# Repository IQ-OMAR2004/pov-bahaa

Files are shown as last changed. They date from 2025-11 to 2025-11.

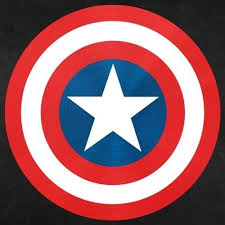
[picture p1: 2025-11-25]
images/captain_america.jpeg

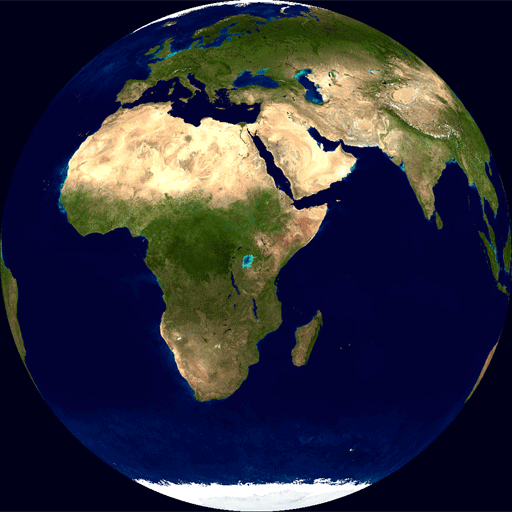
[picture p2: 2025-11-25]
gif_sequences/earth/frame_16.png

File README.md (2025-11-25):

# POV Holographic Fan Display

A Persistence of Vision (POV) display system for Raspberry Pi with WS2815 LED strips.
HEllo from bahaa
## Features

- **Static Images**: Display pre-processed images from `.npy` files
- **GIF Animations**: Play animated sequences
- **Shape Generation**: Built-in circle and square shapes
- **Button Controls**: Switch modes with physical buttons
- **Robust Timing**: Noise filtering and RPM smoothing for stable display
- **Configurable**: Easy configuration through `config.py`

## Hardware Requirements

### Components

| Component | Specification | GPIO Pin |
|---|---|---|
| LED Strip | WS2815, 72 LEDs | GPIO 18 (PWM) |
| Hall Sensor | A3144 or similar | GPIO 4 |
| Button 1 | Circle mode | GPIO 17 |
| Button 2 | Square mode | GPIO 27 |
| Button 3 | Image/GIF cycle | GPIO 22 |

### Wiring Diagram

```
Raspberry Pi               Components
─────────────              ──────────
GPIO 18 (Pin 12) ────────> LED Strip Data In
GPIO 4  (Pin 7)  ────────> Hall Sensor Output
GPIO 17 (Pin 11) ────────> Button 1 (to GND)
GPIO 27 (Pin 13) ────────> Button 2 (to GND)
GPIO 22 (Pin 15) ────────> Button 3 (to GND)
5V      (Pin 2)  ────────> LED Strip VCC
GND     (Pin 6)  ────────> LED Strip GND, Hall Sensor GND
3.3V    (Pin 1)  ────────> Hall Sensor VCC
```

### Notes

- **Power**: WS2815 LEDs require 12V power supply. Use a separate power supply for the LED strip, sharing only GND with the Pi.
- **Level Shifter**: Recommended for 3.3V to 5V data line conversion (though many WS2815 work without it).
- **Hall Sensor**: Place magnet on rotating blade to trigger once per rotation.
- **Buttons**: Connect between GPIO and GND (internal pull-ups are enabled).

## Installation

### 1. Clone or copy the project

```bash
cd /home/pi
git clone <repository-url> POV-new
cd POV-new
```

### 2. Install dependencies

```bash
sudo pip3 install -r requirements.txt
```

### 3. Enable SPI/PWM (if not already)

```bash
sudo raspi-config
# Navigate to: Interface Options > SPI > Enable
# Reboot after changes
```

## Configuration

Edit `config.py` to customize your setup:

```python
# Key settings to adjust:

NUM_LEDS = 72              # Number of LEDs on your strip
NUM_DIVISIONS = 100        # Angular resolution (reduce for faster motors)
BRIGHTNESS_RATIO = 0.3     # Brightness (0.0-1.0)
DEFAULT_RPM = 600          # Expected motor RPM
LINES_TO_SHIFT = -15       # Adjust if image appears rotated
```

### RPM vs Divisions Guide

| Motor RPM | Recommended Divisions |
|---|---|
| 300-600 | 100 (best quality) |
| 600-900 | 50 |
| 900-1200  | 36 |
| 1200-1500 | 24 |
| 1500+ | 16 |

## Usage

### Running the Display

```bash
# Must run as root for GPIO/PWM access
sudo python3 pov_display.py
```

### Controls

- **Button 1 (GPIO 17)**: Switch to circle mode (press again to change color)
- **Button 2 (GPIO 27)**: Switch to square mode (press again to change color)
- **Button 3 (GPIO 22)**: Cycle through images and GIF sequences

### Keyboard

- **Ctrl+C**: Graceful shutdown

## Processing Your Own Images

### Static Images

1. Place your image in the `images/` folder
2. Run the processor:

```bash
python3 process_image.py images/myimage.png
```

3. Output saves to `colors/douple_resolution/douple_res_myimage.npy`

### GIF Animations

1. Place your GIF in the `gifs/` folder
2. Run the processor:

```bash
python3 process_gif.py gifs/myanimation.gif
```

3. Output saves to `gif_colors/myanimation/`

### Image Tips

- **Square images** work best (circular crop is applied)
- **Simple, high-contrast** designs are most visible
- **Centered designs** display better
- Image is sampled radially from center outward

## File Structure

```
POV-new/
├── pov_display.py          # Main display script
├── config.py               # Configuration settings
├── process_image.py        # Static image processor
├── process_gif.py          # GIF/animation processor
├── requirements.txt        # Python dependencies
├── README.md               # This file
├── images/                 # Source images
│   └── Smiley_face.png
├── colors/                 # Processed static images
│   └── douple_resolution/
│       └── douple_res_Smiley_face.npy
├── gifs/                   # Source GIF files
│   └── earth.gif
├── gif_sequences/          # Extracted GIF frames
│   └── earth/
├── gif_colors/             # Processed GIF sequences
│   └── earth/
└── 3d_printing_files/      # CAD files for hardware
```

## Troubleshooting

### Display not showing / flickering

1. **Check power supply**: LEDs need adequate current (72 LEDs × 60mA = 4.3A max)
2. **Reduce brightness**: Lower `BRIGHTNESS_RATIO` in `config.py`
3. **Reduce divisions**: Lower `NUM_DIVISIONS` for faster motors
4. **Check connections**: Ensure GND is shared between Pi and LED strip

### Image appears rotated

Adjust `LINES_TO_SHIFT` in `config.py` (positive or negative values)

### Unstable RPM readings

1. Check hall sensor placement and magnet strength
2. Increase `HALL_DEBOUNCE_US` in config
3. Increase `RPM_HISTORY_SIZE` for more smoothing

### Colors look wrong

Your LED strip might use RGB instead of GRB. Set `LED_IS_GRB = False` in `config.py`

### Permission denied

Always run with `sudo`:
```bash
sudo python3 pov_display.py
```

## Advanced: Creating Custom Shapes

You can add custom shape generators in `pov_display.py`:

```python
def generate_custom_shape(color_rgb=(255, 255, 255)):
    data = []
    for angle_idx in range(NUM_DIVISIONS):
        line = [make_color(0, 0, 0)] * NUM_LEDS
        # Your shape logic here
        # Set pixels: line[led_position] = make_color(r, g, b)
        data.append(line)
    return data
```

## License

MIT License - Feel free to modify and share!

## Credits

Combined from POV-new and Pov-fan projects for optimal performance.

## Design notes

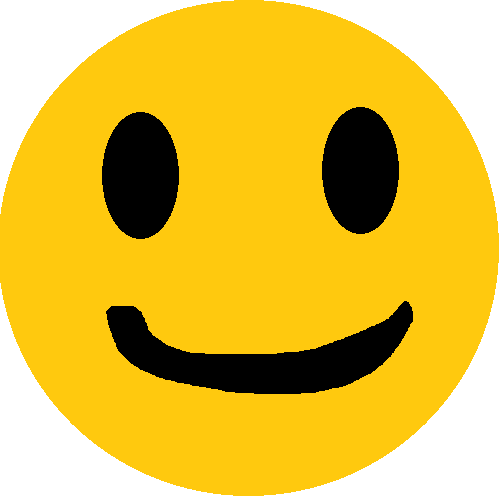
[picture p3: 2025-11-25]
images/Smiley_face.png

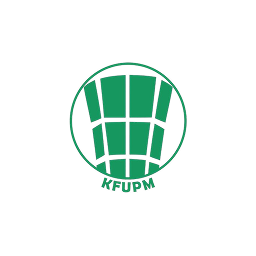
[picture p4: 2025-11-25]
images/kfupm_pp.png

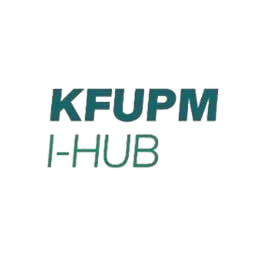
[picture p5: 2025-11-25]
images/kfupmihub.png

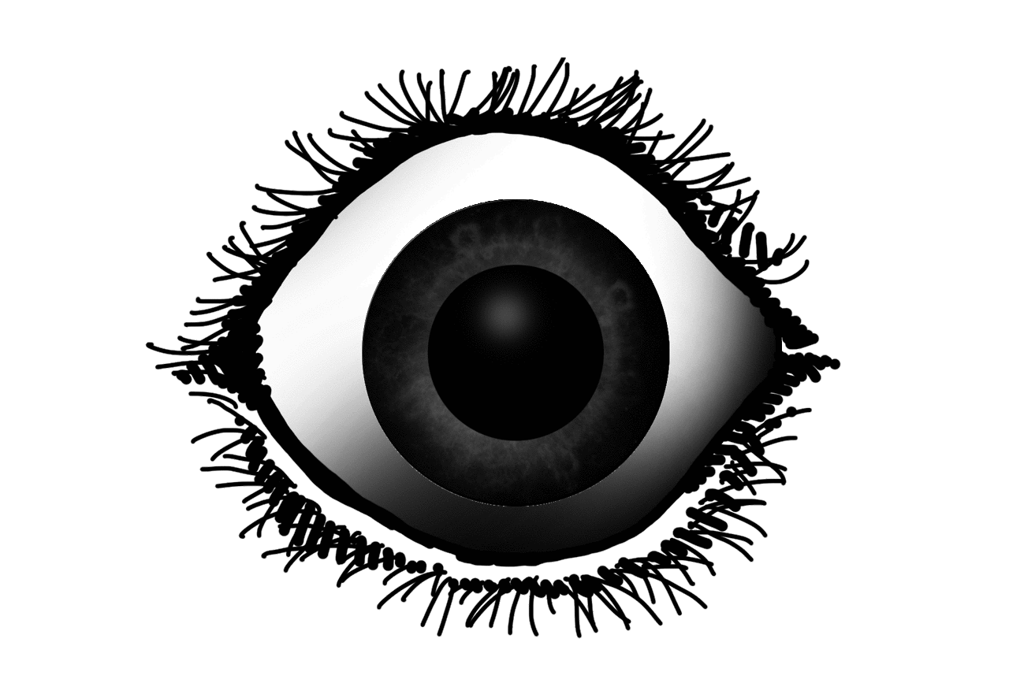
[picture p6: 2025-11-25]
gif_sequences/eyegif/frame_5.png

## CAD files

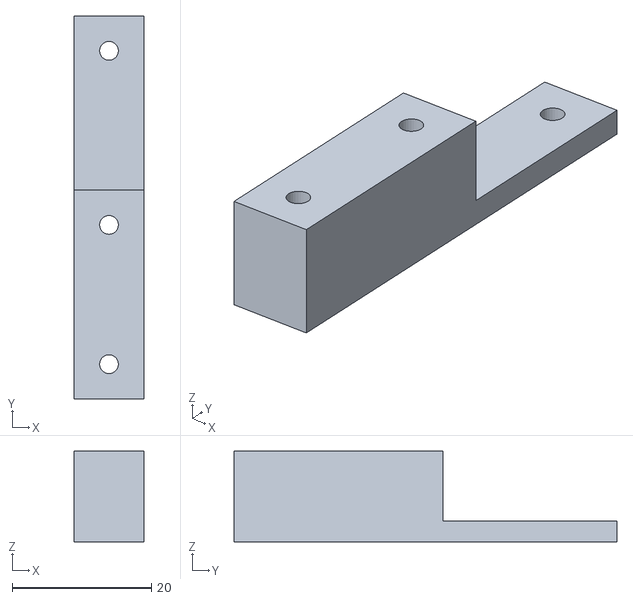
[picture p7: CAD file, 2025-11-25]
3d_printing_files/sensor_connector.stl
10.0 x 55.0 x 13.0

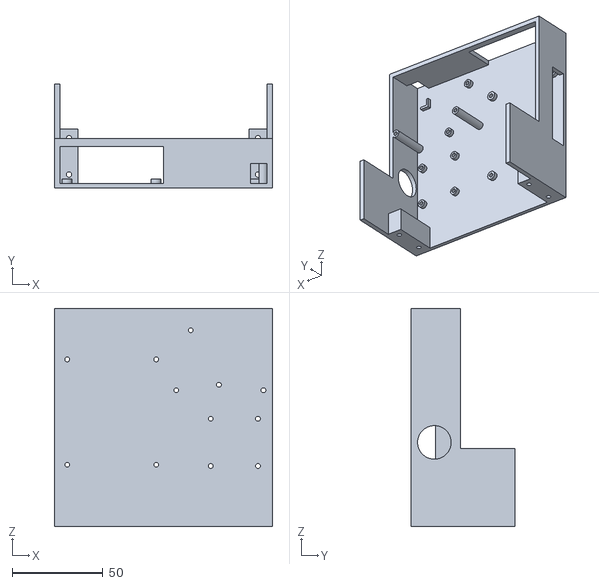
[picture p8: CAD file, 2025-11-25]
3d_printing_files/base_blue_print.STL
120.0 x 57.5 x 120.0

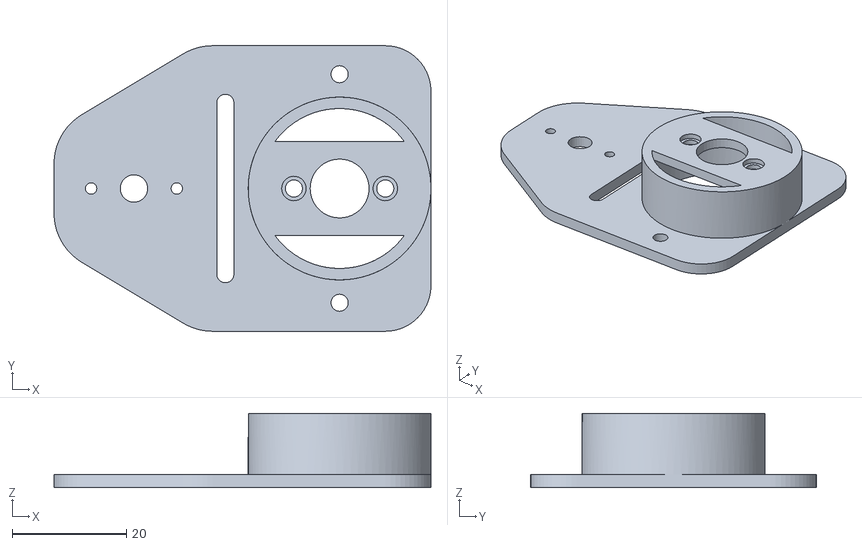
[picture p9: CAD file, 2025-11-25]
3d_printing_files/fan_motor_connector v5.stl
66.0 x 50.0 x 13.0

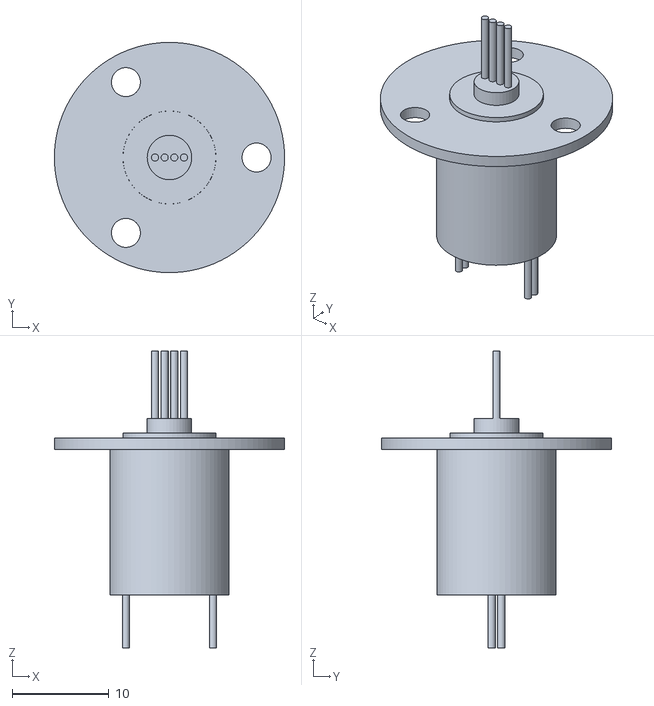
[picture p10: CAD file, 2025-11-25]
3d_printing_files/Slip_ring v1.stl
23.8 x 23.8 x 30.7

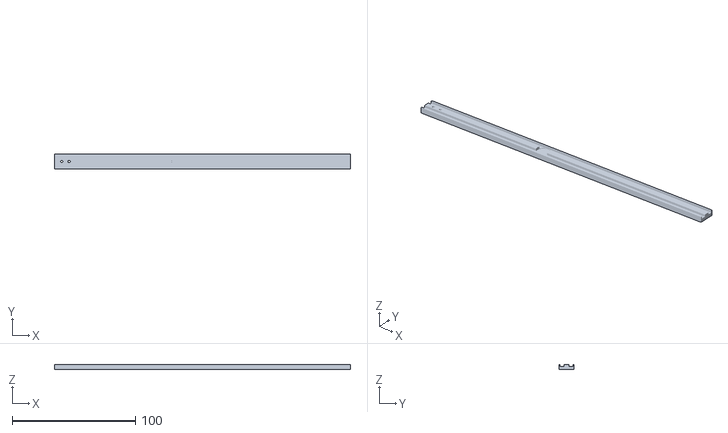
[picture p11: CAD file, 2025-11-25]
3d_printing_files/Blad v4.stl
240.0 x 12.0 x 4.13

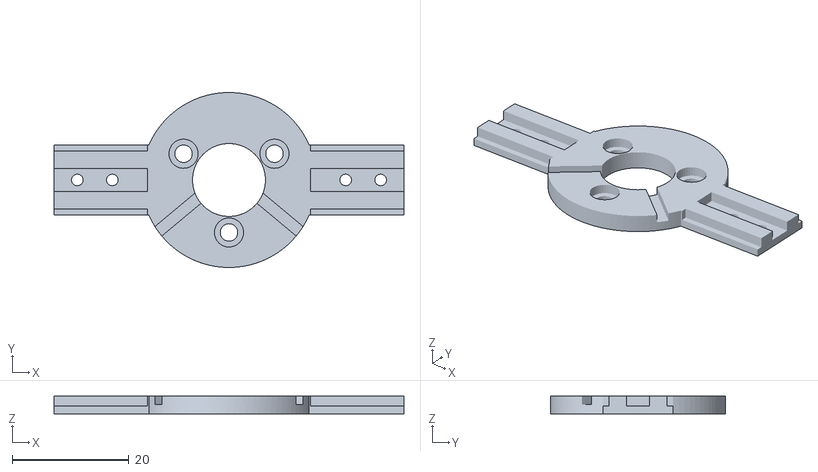
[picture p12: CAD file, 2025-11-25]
3d_printing_files/fan_blades_holder v1.stl
60.0 x 30.0 x 3.00

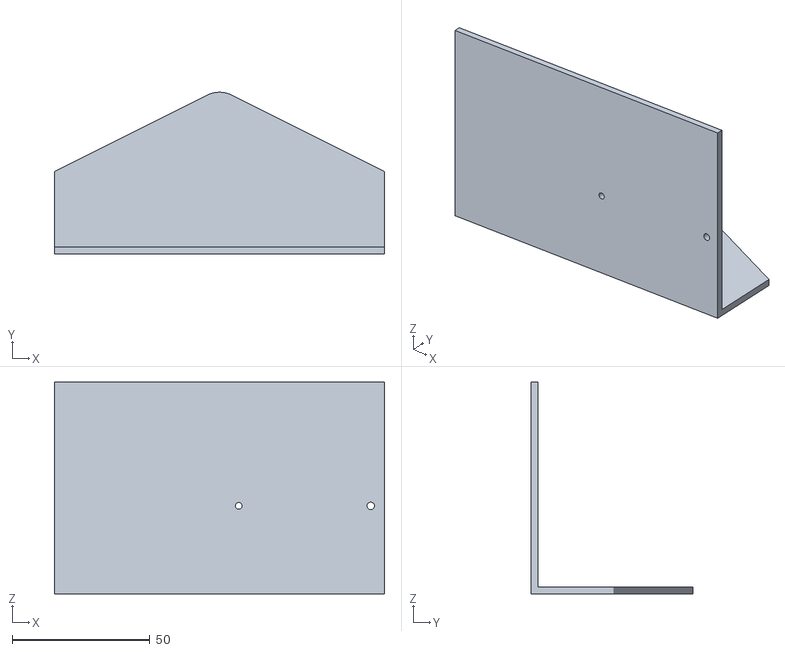
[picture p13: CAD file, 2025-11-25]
3d_printing_files/base_cover.STL
120.0 x 58.8 x 77.0

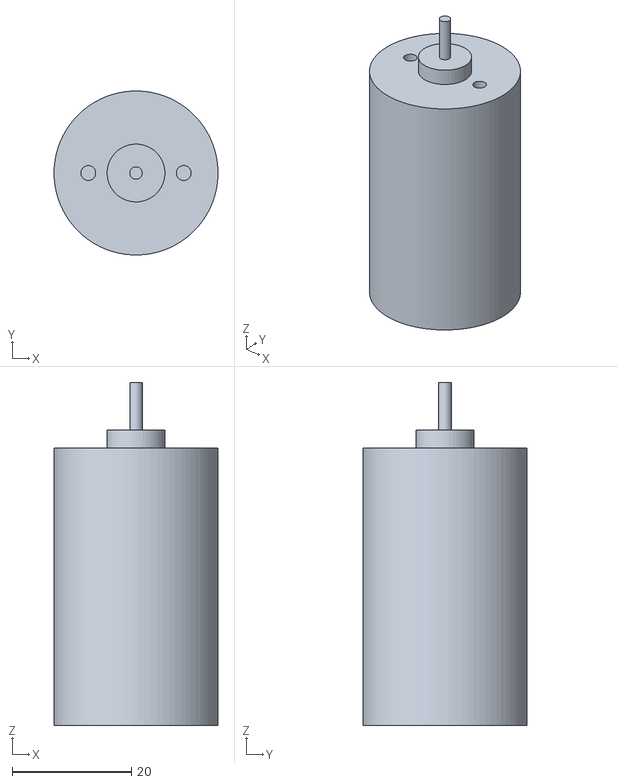
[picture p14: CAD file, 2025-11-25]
3d_printing_files/Large_motor v1.stl
27.5 x 27.5 x 57.5

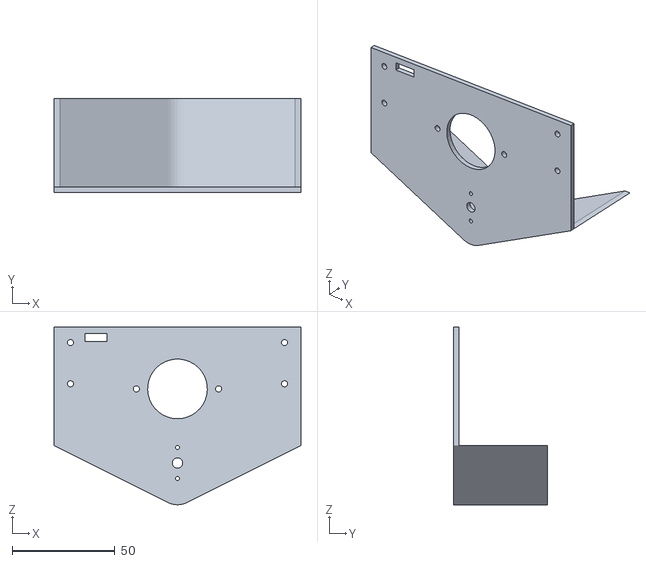
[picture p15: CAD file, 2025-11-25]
3d_printing_files/base_front.STL
120.0 x 45.5 x 86.3

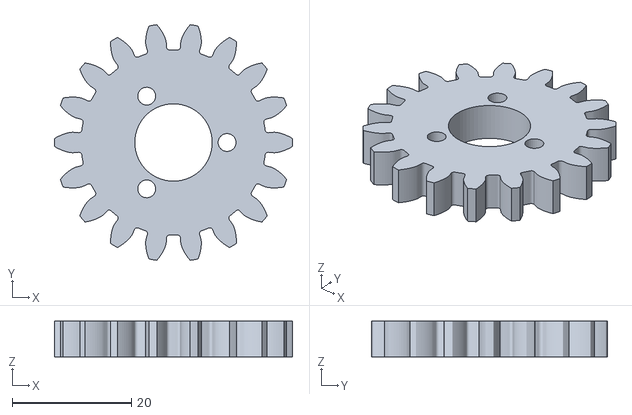
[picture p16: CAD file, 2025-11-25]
3d_printing_files/Gear_1 v3.stl
40.0 x 39.6 x 6.00

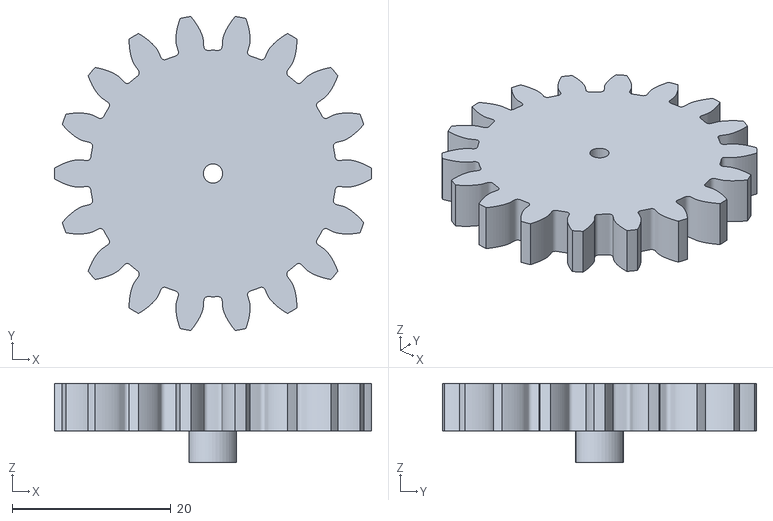
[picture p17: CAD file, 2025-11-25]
3d_printing_files/Gear_2 v3.stl
40.0 x 39.6 x 10.0

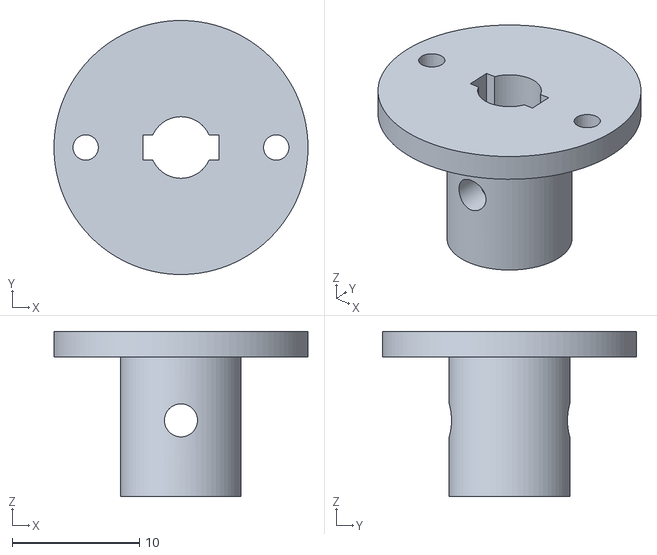
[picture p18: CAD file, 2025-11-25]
3d_printing_files/slip_ring_extension v7.stl
20.0 x 20.0 x 13.0

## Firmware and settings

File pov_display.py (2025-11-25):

#!/usr/bin/env python3
"""
POV Holographic Fan Display - Combined & Optimized
===================================================
Combines functionality from POV-new (image/GIF loading) with 
Pov-fan hardware configuration (pins, buttons, timing).

Features:
- Load pre-processed .npy images (static images)
- GIF/animation sequence playback
- Shape generation (circle, square)
- Button controls for mode switching
- Robust RPM filtering and noise rejection
- Optimized timing for stable display

Hardware:
- WS2815 LED Strip (72 LEDs) on GPIO 18
- Hall Sensor (A3144) on GPIO 4
- Button 1 (Circle) on GPIO 17
- Button 2 (Square) on GPIO 27  
- Button 3 (Image/Next) on GPIO 22

Author: Combined from POV-new and Pov-fan projects
"""

import time
import os
import math
import threading
from rpi_ws281x import PixelStrip, Color
import numpy as np
import RPi.GPIO as GPIO

# ============== LOAD CONFIGURATION ==============
# Try to import from config.py, fall back to defaults if not found
try:
    from config import (
        NUM_LEDS, LED_PIN, LED_FREQ_HZ, LED_DMA, LED_BRIGHTNESS,
        LED_INVERT, LED_CHANNEL, LED_IS_GRB,
        HALL_SENSOR_PIN, BUTTON_CIRCLE, BUTTON_SQUARE, BUTTON_IMAGE,
        NUM_DIVISIONS, BRIGHTNESS_RATIO, LINES_TO_SHIFT,
        LED_UPDATE_TIME_US, DEFAULT_RPM, MIN_RPM, MAX_RPM, TIMING_MARGIN_US,
        HALL_DEBOUNCE_US, MAX_RPM_CHANGE_PERCENT, RPM_HISTORY_SIZE,
        STATIC_IMAGES_PATH, GIF_COLORS_PATH, ROT_PER_FRAME,
        BUTTON_DEBOUNCE_TIME
    )
    print("✓ Loaded configuration from config.py")
except ImportError:
    print("⚠ config.py not found, using default values")
    # ============== DEFAULT CONFIGURATION ==============
    NUM_LEDS = 72
    LED_PIN = 18
    LED_FREQ_HZ = 800000
    LED_DMA = 10
    LED_BRIGHTNESS = 150
    LED_INVERT = False
    LED_CHANNEL = 0
    LED_IS_GRB = True
    HALL_SENSOR_PIN = 4
    BUTTON_CIRCLE = 17
    BUTTON_SQUARE = 27
    BUTTON_IMAGE = 22
    NUM_DIVISIONS = 100
    BRIGHTNESS_RATIO = 0.3
    LINES_TO_SHIFT = -15
    LED_UPDATE_TIME_US = 2800
    DEFAULT_RPM = 600
    MIN_RPM = 200
    MAX_RPM = 1500
    TIMING_MARGIN_US = 300
    HALL_DEBOUNCE_US = 5000
    MAX_RPM_CHANGE_PERCENT = 40
    RPM_HISTORY_SIZE = 15
    STATIC_IMAGES_PATH = "colors/douple_resolution/"
    GIF_COLORS_PATH = "gif_colors/"
    ROT_PER_FRAME = 4
    BUTTON_DEBOUNCE_TIME = 0.3

# ============== GLOBAL VARIABLES ==============

# Display modes
MODES = ["circle", "square", "static_image", "gif_sequence"]
current_mode_index = 0
current_mode = MODES[0]

# Image/sequence data
static_images = []               # List of available static images
gif_sequences = []               # List of available GIF sequences
current_static_index = 0
current_gif_index = 0
current_frame_index = 0
rot_per_frame = ROT_PER_FRAME    # Rotations before advancing GIF frame

# Display buffer
display_data = []                # Current frame to display [divisions][leds]
sequence_colors = []             # All frames for GIF sequence

# Timing variables
last_rotation_micros = 0
rotation_time_micros = int(60_000_000 / DEFAULT_RPM)
time_per_line_micros = rotation_time_micros // NUM_DIVISIONS
current_line = 0
rotation_active = False

# RPM tracking
current_rpm = DEFAULT_RPM
stable_rpm = DEFAULT_RPM
rpm_history = []
last_rpm_print_time = time.monotonic()


# Counters
rotation_count = 0
valid_rotation_count = 0
noise_rejected_count = 0
missed_lines_count = 0

# Hall sensor tracking
last_hall_state = GPIO.LOW
last_hall_trigger_time = 0

# Button tracking
last_button_states = {
    BUTTON_CIRCLE: GPIO.HIGH,
    BUTTON_SQUARE: GPIO.HIGH,
    BUTTON_IMAGE: GPIO.HIGH
}
last_button_time = {
    BUTTON_CIRCLE: 0,
    BUTTON_SQUARE: 0,
    BUTTON_IMAGE: 0
}
DEBOUNCE_TIME = BUTTON_DEBOUNCE_TIME

# Threading event for rotation sync
rotation_end_event = threading.Event()



# ============== GPIO SETUP ==============
GPIO.setmode(GPIO.BCM)
GPIO.setwarnings(False)

try:
    GPIO.cleanup()
    time.sleep(0.1)
except:
    pass

GPIO.setmode(GPIO.BCM)
GPIO.setup(HALL_SENSOR_PIN, GPIO.IN, pull_up_down=GPIO.PUD_DOWN)
GPIO.setup(BUTTON_CIRCLE, GPIO.IN, pull_up_down=GPIO.PUD_UP)
GPIO.setup(BUTTON_SQUARE, GPIO.IN, pull_up_down=GPIO.PUD_UP)
GPIO.setup(BUTTON_IMAGE, GPIO.IN, pull_up_down=GPIO.PUD_UP)

# Initialize LED strip
strip = PixelStrip(NUM_LEDS, LED_PIN, LED_FREQ_HZ, LED_DMA, LED_INVERT, LED_BRIGHTNESS, LED_CHANNEL)
strip.begin()


# ============== UTILITY FUNCTIONS ==============

def make_color(r, g, b):
    """Create color value handling GRB vs RGB order"""
    if LED_IS_GRB:
        return Color(int(g), int(r), int(b))
    else:
        return Color(int(r), int(g), int(b))


def clear_strip():
    """Turn off all LEDs"""
    for i in range(NUM_LEDS):
        strip.setPixelColor(i, make_color(0, 0, 0))
    strip.show()


def get_time_micros():
    """Get current time in microseconds"""
    return int(time.perf_counter() * 1_000_000)


def precise_micros_delay(micros_to_delay):
    """Precise busy-wait delay in microseconds"""
    start = time.perf_counter() * 1_000_000
    while (time.perf_counter() * 1_000_000 - start) < micros_to_delay:
        if rotation_end_event.is_set():
            break


# ============== FILE DISCOVERY ==============

def discover_static_images():
    """Find all .npy files in the static images directory"""
    global static_images
    static_images = []
    
    if os.path.exists(STATIC_IMAGES_PATH):
        for f in sorted(os.listdir(STATIC_IMAGES_PATH)):
            if f.endswith('.npy'):
                static_images.append(f)
    
    print(f"Found {len(static_images)} static images")
    return static_images


def discover_gif_sequences():
    """Find all GIF sequence folders"""
    global gif_sequences
    gif_sequences = []
    
    if os.path.exists(GIF_COLORS_PATH):
        for d in sorted(os.listdir(GIF_COLORS_PATH)):
            path = os.path.join(GIF_COLORS_PATH, d)
            if os.path.isdir(path):
                # Check if it has .npy files
                npy_files = [f for f in os.listdir(path) if f.endswith('.npy')]
                if npy_files:
                    gif_sequences.append(d)
    
    print(f"Found {len(gif_sequences)} GIF sequences")
    return gif_sequences


# ============== NPY IMAGE LOADING (from POV-new) ==============

def load_npy_image(npy_path):
    """
    Load a pre-processed .npy image file and convert to display format.
    
    The .npy files contain color data in format:
    [num_divisions][num_leds][3] where [3] is RGB
    """
    try:
        slices_colors = np.load(npy_path)
        slices_colors = slices_colors.tolist()
        return arrange_colors_for_display(slices_colors)
    except Exception as e:
        print(f"Error loading {npy_path}: {e}")
        return None


def arrange_colors_for_display(slices_colors):
    """
    Arrange colors from .npy format to display format.
    Handles the two-sided LED strip arrangement.
    
    The strip has two halves:
    - LEDs 0 to 35: One side (inner to outer)
    - LEDs 36 to 71: Other side (inner to outer)
    """
    arranged_colors = []
    num_leds_one_side = NUM_LEDS // 2
    num_divs = len(slices_colors)
    
    for line_iter in range(num_divs):
        line_array = [make_color(0, 0, 0) for _ in range(NUM_LEDS)]
        
        # First half of strip (reversed - outer LEDs first in data)
        for i in range(num_leds_one_side):
            if i * 2 + 1 < len(slices_colors[line_iter]):
                color_arr = slices_colors[line_iter][i * 2 + 1]
                color = make_color(
                    int(color_arr[0] * BRIGHTNESS_RATIO),
                    int(color_arr[1] * BRIGHTNESS_RATIO),
                    int(color_arr[2] * BRIGHTNESS_RATIO)
                )
                line_array[num_leds_one_side - i - 1] = color
        
        # Second half of strip (opposite angle, 180 degrees offset)
        opposite_line = (line_iter + num_divs // 2) % num_divs
        for i in range(num_leds_one_side):
            if i * 2 < len(slices_colors[opposite_line]):
                color_arr = slices_colors[opposite_line][i * 2]
                color = make_color(
                    int(color_arr[0] * BRIGHTNESS_RATIO),
                    int(color_arr[1] * BRIGHTNESS_RATIO),
                    int(color_arr[2] * BRIGHTNESS_RATIO)
                )
                line_array[num_leds_one_side + i] = color
        
        arranged_colors.append(line_array)
    
    return arranged_colors


def load_gif_sequence(sequence_name):
    """
    Load all frames of a GIF sequence.
    Returns list of arranged color arrays (one per frame).
    """
    global sequence_colors, current_frame_index
    
    sequence_path = os.path.join(GIF_COLORS_PATH, sequence_name)
    if not os.path.exists(sequence_path):
        print(f"Sequence not found: {sequence_path}")
        return None
    
    files = sorted([f for f in os.listdir(sequence_path) if f.endswith('.npy')])
    if not files:
        print(f"No .npy files in: {sequence_path}")
        return None
    
    sequence_colors = []
    for frame_file in files:
        frame_path = os.path.join(sequence_path, frame_file)
        frame_data = load_npy_image(frame_path)
        if frame_data:
            sequence_colors.append(frame_data)
    
    current_frame_index = 0
    print(f"Loaded GIF sequence '{sequence_name}' with {len(sequence_colors)} frames")
    return sequence_colors


# ============== SHAPE GENERATION (from Pov-fan) ==============

def generate_circle_data(radius_leds=28, color_rgb=(0, 255, 255)):
    """Generate circle display data"""
    data = []
    center_led = NUM_LEDS // 2
    r, g, b = color_rgb
    
    circle_thickness = max(2, 5 - NUM_DIVISIONS // 30)
    pixel_color = make_color(r * BRIGHTNESS_RATIO, g * BRIGHTNESS_RATIO, b * BRIGHTNESS_RATIO)
    off_color = make_color(0, 0, 0)
    
    for angle_idx in range(NUM_DIVISIONS):
        line = [off_color] * NUM_LEDS
        
        if radius_leds < NUM_LEDS // 2:
            for offset in range(-circle_thickness // 2, circle_thickness // 2 + 1):
                led_pos_1 = center_led - radius_leds + offset
                led_pos_2 = center_led + radius_leds + offset
                
                if 0 <= led_pos_1 < NUM_LEDS:
                    line[led_pos_1] = pixel_color
                if 0 <= led_pos_2 < NUM_LEDS:
                    line[led_pos_2] = pixel_color
        
        data.append(line)
    
    return data


def generate_square_data(side_length_leds=24, color_rgb=(255, 0, 255)):
    """Generate square display data using polar math"""
    data = []
    center_led = NUM_LEDS // 2
    r, g, b = color_rgb
    
    edge_thickness = max(2, 5 - NUM_DIVISIONS // 30)
    half_side = side_length_leds // 2
    
    pixel_color = make_color(r * BRIGHTNESS_RATIO, g * BRIGHTNESS_RATIO, b * BRIGHTNESS_RATIO)
    off_color = make_color(0, 0, 0)
    
    for angle_idx in range(NUM_DIVISIONS):
        line = [off_color] * NUM_LEDS
        
        angle_rad = (angle_idx * 2 * math.pi / NUM_DIVISIONS)
        cos_a = abs(math.cos(angle_rad))
        sin_a = abs(math.sin(angle_rad))
        max_trig = max(cos_a, sin_a, 0.001)
        
        distance = int(half_side / max_trig)
        distance = min(distance, center_led - 2)
        
        for offset in range(-edge_thickness // 2, edge_thickness // 2 + 1):
            led_pos_1 = center_led - distance + offset
            led_pos_2 = center_led + distance + offset
            
            if 0 <= led_pos_1 < NUM_LEDS:
                line[led_pos_1] = pixel_color
            if 0 <= led_pos_2 < NUM_LEDS:
                line[led_pos_2] = pixel_color
        
        data.append(line)
    
    return data


def generate_filled_circle_data(radius_leds=28, color_rgb=(0, 100, 255)):
    """Generate filled circle (disk) display data"""
    data = []
    center_led = NUM_LEDS // 2
    r, g, b = color_rgb
    
    pixel_color = make_color(r * BRIGHTNESS_RATIO, g * BRIGHTNESS_RATIO, b * BRIGHTNESS_RATIO)
    off_color = make_color(0, 0, 0)
    
    for angle_idx in range(NUM_DIVISIONS):
        line = [off_color] * NUM_LEDS
        
        # Fill from center to radius
        for dist in range(radius_leds):
            led_pos_1 = center_led - dist - 1
            led_pos_2 = center_led + dist
            
            if 0 <= led_pos_1 < NUM_LEDS:
                line[led_pos_1] = pixel_color
            if 0 <= led_pos_2 < NUM_LEDS:
                line[led_pos_2] = pixel_color
        
        data.append(line)
    
    return data


# ============== MODE SWITCHING ==============

def set_mode_circle():
    """Switch to circle shape mode"""
    global display_data, current_mode
    current_mode = "circle"
    display_data = generate_circle_data(radius_leds=28, color_rgb=(0, 255, 255))
    print("Mode: CIRCLE (cyan)")
    flash_mode_change()


def set_mode_square():
    """Switch to square shape mode"""
    global display_data, current_mode
    current_mode = "square"
    display_data = generate_square_data(side_length_leds=24, color_rgb=(255, 0, 255))
    print("Mode: SQUARE (magenta)")
    flash_mode_change()


def set_mode_static_image():
    """Switch to static image mode"""
    global display_data, current_mode, current_static_index
    
    if not static_images:
        print("No static images found!")
        return
    
    current_mode = "static_image"
    img_file = static_images[current_static_index]
    img_path = os.path.join(STATIC_IMAGES_PATH, img_file)
    
    loaded = load_npy_image(img_path)
    if loaded:
        display_data = loaded
        print(f"Mode: STATIC IMAGE - {img_file}")
    else:
        display_data = generate_circle_data()
    flash_mode_change()


def set_mode_gif_sequence():
    """Switch to GIF sequence mode"""
    global display_data, current_mode, current_gif_index, sequence_colors, current_frame_index
    
    if not gif_sequences:
        print("No GIF sequences found!")
        return
    
    current_mode = "gif_sequence"
    seq_name = gif_sequences[current_gif_index]
    
    loaded = load_gif_sequence(seq_name)
    if loaded:
        display_data = sequence_colors[0]
        current_frame_index = 0
        print(f"Mode: GIF SEQUENCE - {seq_name} ({len(sequence_colors)} frames)")
    else:
        display_data = generate_circle_data()
    flash_mode_change()


def cycle_content():
    """Cycle to next content in current mode"""
    global current_static_index, current_gif_index, display_data
    
    if current_mode == "static_image" and static_images:
        current_static_index = (current_static_index + 1) % len(static_images)
        set_mode_static_image()
    elif current_mode == "gif_sequence" and gif_sequences:
        current_gif_index = (current_gif_index + 1) % len(gif_sequences)
        set_mode_gif_sequence()
    elif current_mode == "circle":
        # Cycle circle colors
        colors = [(0, 255, 255), (255, 255, 0), (255, 0, 255), (0, 255, 0)]
        display_data = generate_circle_data(radius_leds=28, color_rgb=colors[rotation_count % len(colors)])
        print(f"Circle color changed")
        flash_mode_change()
    elif current_mode == "square":
        colors = [(255, 0, 255), (255, 255, 0), (0, 255, 255), (255, 128, 0)]
        display_data = generate_square_data(side_length_leds=24, color_rgb=colors[rotation_count % len(colors)])
        print(f"Square color changed")
        flash_mode_change()


# ============== BUTTON HANDLING ==============

def flash_mode_change():
    """Flash LEDs to indicate mode change and show preview"""
    # Brief flash of white to indicate change
    for i in range(NUM_LEDS):
        strip.setPixelColor(i, make_color(50, 50, 50))
    strip.show()
    time.sleep(0.1)
    
    # Show a static preview of the new mode (first line of display_data)
    show_static_preview()


def show_static_preview():
    """Show a static preview of current display_data on LEDs"""
    global display_data
    
    if not display_data or len(display_data) == 0:
        return
    
    # Show the first line (or middle line for better preview)
    preview_line = len(display_data) // 4  # Show at 90 degrees for variety
    
    if preview_line < len(display_data):
        line_data = display_data[preview_line]
        for i in range(min(NUM_LEDS, len(line_data))):
            strip.setPixelColor(i, line_data[i])
        strip.show()


def check_buttons():
    """Poll buttons for mode changes"""
    global last_button_states, last_button_time, current_static_index, current_mode
    
    current_time = time.time()
    
    # Button 1: Circle mode
    state = GPIO.input(BUTTON_CIRCLE)
    if state == GPIO.LOW and last_button_states[BUTTON_CIRCLE] == GPIO.HIGH:
        if current_time - last_button_time[BUTTON_CIRCLE] > DEBOUNCE_TIME:
            if current_mode == "circle":
                cycle_content()
            else:
                set_mode_circle()
            last_button_time[BUTTON_CIRCLE] = current_time
    last_button_states[BUTTON_CIRCLE] = state
    
    # Button 2: Square mode
    state = GPIO.input(BUTTON_SQUARE)
    if state == GPIO.LOW and last_button_states[BUTTON_SQUARE] == GPIO.HIGH:
        if current_time - last_button_time[BUTTON_SQUARE] > DEBOUNCE_TIME:
            if current_mode == "square":
                cycle_content()
            else:
                set_mode_square()
            last_button_time[BUTTON_SQUARE] = current_time
    last_button_states[BUTTON_SQUARE] = state
    
    # Button 3: Image/GIF mode (cycles through modes and content)
    state = GPIO.input(BUTTON_IMAGE)
    if state == GPIO.LOW and last_button_states[BUTTON_IMAGE] == GPIO.HIGH:
        if current_time - last_button_time[BUTTON_IMAGE] > DEBOUNCE_TIME:
            if current_mode == "static_image":
                if static_images and current_static_index < len(static_images) - 1:
                    cycle_content()
                else:
                    set_mode_gif_sequence()
            elif current_mode == "gif_sequence":
                if gif_sequences and current_gif_index < len(gif_sequences) - 1:
                    cycle_content()
                else:
                    # Cycle back to static images
                    current_static_index = 0
                    set_mode_static_image()
            else:
                # From shapes, go to static images
                current_static_index = 0
                set_mode_static_image()
            last_button_time[BUTTON_IMAGE] = current_time
    last_button_states[BUTTON_IMAGE] = state


# ============== HALL SENSOR HANDLING ==============
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

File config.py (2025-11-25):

"""
POV Display Configuration
=========================
Edit this file to customize your POV fan display settings.
All configuration values are centralized here for easy modification.
"""

# ============== LED STRIP CONFIGURATION ==============
NUM_LEDS = 72                    # Total LEDs on your strip
LED_PIN = 18                     # GPIO pin (must support PWM: 18, 12, 13, 19)
LED_FREQ_HZ = 800000             # Signal frequency (usually 800kHz for WS28xx)
LED_DMA = 10                     # DMA channel (usually 10)
LED_BRIGHTNESS = 150             # Initial brightness (0-255)
LED_INVERT = False               # True if using level shifter that inverts
LED_CHANNEL = 0                  # 0 for GPIO 18/12, 1 for GPIO 13/19

# Color order - WS2815 typically uses GRB
# Set to True for GRB strips, False for RGB strips
LED_IS_GRB = True

# ============== SENSOR PINS ==============
HALL_SENSOR_PIN = 4              # Hall effect sensor (A3144 or similar)

# ============== BUTTON PINS ==============
# Set to None to disable a button
BUTTON_CIRCLE = 17               # Circle shape button
BUTTON_SQUARE = 27               # Square shape button
BUTTON_IMAGE = 22                # Image/GIF cycle button

# ============== DISPLAY SETTINGS ==============
# Number of angular divisions per rotation
# ACTUAL maximums based on 72 LEDs and 2800µs update time:
#   70 divisions: ~300 RPM
#   50 divisions: ~420 RPM
#   40 divisions: ~530 RPM
#   30 divisions: ~700 RPM
#   24 divisions: ~870 RPM
#   16 divisions: ~1300 RPM
NUM_DIVISIONS = 40  # Optimized for 500 RPM (max ~42)

# Brightness multiplier (0.0 to 1.0)
# Lower values = dimmer but less power usage
# Higher values = brighter but may cause flickering at high RPM
BRIGHTNESS_RATIO = 0.3

# Rotational offset to align image with starting position
# Adjust this if your image appears rotated
# Sensor is 30° from LED center, so offset by ~3 lines (30°/9° per line)
LINES_TO_SHIFT = -13  # Was -15, adjusted +3 to shift image 30° right

# ============== MOTOR/RPM SETTINGS ==============
# Expected motor RPM (used for initial timing)
DEFAULT_RPM = 500

# Valid RPM range (readings outside this are rejected as noise)
MIN_RPM = 200
MAX_RPM = 1500

# ============== TIMING SETTINGS ==============
# Approximate time to update all LEDs (microseconds)
# Calculated as: NUM_LEDS * 24 bits * 1.25µs + reset time
# For 72 LEDs: ~2800µs
LED_UPDATE_TIME_US = 2800

# Safety margin for timing (microseconds)
TIMING_MARGIN_US = 300

# ============== NOISE FILTERING ==============
# Ignore hall sensor triggers within this time (microseconds)
HALL_DEBOUNCE_US = 5000

# Reject RPM changes larger than this percentage
MAX_RPM_CHANGE_PERCENT = 40

# Number of samples for RPM smoothing (more = smoother but slower response)
RPM_HISTORY_SIZE = 15

# ============== FILE PATHS ==============
# Path to pre-processed static images (.npy files)
STATIC_IMAGES_PATH = "colors/douple_resolution/"

# Path to GIF sequence folders
GIF_COLORS_PATH = "gif_colors/"

# ============== ANIMATION SETTINGS ==============
# Number of rotations before advancing to next GIF frame
# Lower = faster animation, Higher = slower animation
ROT_PER_FRAME = 4

# ============== BUTTON SETTINGS ==============
# Button debounce time (seconds)
BUTTON_DEBOUNCE_TIME = 0.3

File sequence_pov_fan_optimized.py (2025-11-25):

import time
from rpi_ws281x import PixelStrip, Color
import numpy as np
import RPi.GPIO as GPIO
from apscheduler.schedulers.background import BackgroundScheduler
from apscheduler.triggers.interval import IntervalTrigger
import threading
import os

# Configuration

NUM_LEDS_TOTAL = 72
# Use either 72 for douple resolution or 36 for single resolution
NUM_LEDS_TO_ACTIVATE = 72 # The number of the LEDs to activate in the fan (the rest will be off)
NUM_LEDS_TO_USE = 72 # The number of the LEDs to use in the fan (the rest will be off) 
# NUM_LEDS_TO_ACTIVATE = 36 # The number of the LEDs to activate in the fan (the rest will be off)
# NUM_LEDS_TO_USE = 36 # The number of the LEDs to use in the fan (the rest will be off)

BRIGHTNESS_RATIO = 0.2
NUM_DIVS = 100  # Number of divisions (lines) in one full rotation
palette_size = 10
if NUM_LEDS_TO_ACTIVATE == 36:
    LINES_TO_SHIFT = -24 # This is to align the image properly. Adjust as needed.
else:
    LINES_TO_SHIFT = -18


LED_PIN = 18          # GPIO pin connected to the data line (must support PWM!).
LED_FREQ_HZ = 800000  # LED signal frequency in hertz (usually 800kHz).
LED_DMA = 10          # DMA channel to use for generating signal.
LED_BRIGHTNESS = 50  # Brightness of the LED (0-255).
LED_INVERT = False    # True to invert the signal (for level shifter).
LED_CHANNEL = 0       # Set to 1 for GPIOs 13, 19, 41, 45, 53.


not_received_color = Color(2, 1, 5)
first_line_colors = [Color(5, 5, 0)] * NUM_LEDS_TO_USE
line_to_show_colors = first_line_colors.copy()
line_iter = 0

# POV clock variables
previous_micros = 0
counter_1 = 0
current_count = 0
line_start_time = 0
line_end_time = 0

# Interruption variables to count rotation speed
last_IN_state = 0
one_rot_time = 0
time_per_deg = 0
degs_per_line = 360.0 / NUM_DIVS  # Using 50 divisions


# Timer and delay settings
delay_time_micro = 2000000
line_end = False
num_ms_delay = 20
rotation_end = False
rot_per_frame = 4 # Number of rotations per frame, to display videos or animations


rotation_end_event = threading.Event()
rot_number = 0


# Define the GPIO pin where the interrupt is connected
INTERRUPT_PIN = 4

# Set up the GPIO
GPIO.setmode(GPIO.BCM)
#GPIO.setup(INTERRUPT_PIN, GPIO.IN, pull_up_down=GPIO.PUD_UP)
GPIO.setup(INTERRUPT_PIN, GPIO.IN, pull_up_down=GPIO.PUD_DOWN)

# Initialize LED strip
strip = PixelStrip(NUM_LEDS_TO_ACTIVATE, LED_PIN, LED_FREQ_HZ, LED_DMA, LED_INVERT, LED_BRIGHTNESS, LED_CHANNEL)
strip.begin()

sequence_name = "earth" # Name of the sequence (folder in gif_colors)
path_to_sequence = f"gif_colors/{sequence_name}/"

# Get all frames of the sequence
files = os.listdir(path_to_sequence)

files = sorted(files)
num_frames = len(files)

sequence_colors = np.array([])



num_leds_one_side = NUM_LEDS_TOTAL//2

# Load all frames colors into sequence_colors
for num, image_name in enumerate(files):
    colors_array = []
    image_path = f"gif_colors/{sequence_name}/{image_name}"
    slices_colors = np.load(image_path) 
    slices_colors = slices_colors.tolist()

    for line in range(NUM_DIVS):
        line_array = [Color(0,0,0) for _ in range(NUM_LEDS_TOTAL)]
            
        for i in range(num_leds_one_side):
            color_arr = slices_colors[line][i*2+1]
            corrected_brightness = BRIGHTNESS_RATIO/((num_leds_one_side-i)/10.0)
            corrected_brightness = BRIGHTNESS_RATIO
            color = Color(int(color_arr[1]*corrected_brightness), int(color_arr[0]*corrected_brightness), int(color_arr[2]*corrected_brightness))
            line_array[num_leds_one_side - i - 1] = color
        for i in range(num_leds_one_side):
            corrected_brightness = BRIGHTNESS_RATIO/((num_leds_one_side-i)/10.0)
            corrected_brightness = BRIGHTNESS_RATIO
            color_arr = slices_colors[(line+NUM_DIVS//2)%NUM_DIVS][i*2]
            color = Color(int(color_arr[1]*corrected_brightness), int(color_arr[0]*corrected_brightness), int(color_arr[2]*corrected_brightness))
            line_array[num_leds_one_side+i] = color
        colors_array.append(line_array)
    if num == 0:
        sequence_colors = [colors_array]
    else:
        sequence_colors.append(colors_array)
        


frame_iter = 0    
frame_colors = sequence_colors[frame_iter]


# Precise delay function
def precise_micros_delay(micros_to_delay):
    start = time.perf_counter()*1000000
    end = time.perf_counter()*1000000
    while (end-start)<micros_to_delay and not rotation_end_event.is_set():
        end = time.perf_counter()*1000000
        

def handle_interrupt_rising(channel):
    global counter_1, current_count, one_rot_time, time_per_deg, previous_micros, line_iter, delay_time_micro, rot_number, frame_iter
    current_count = time.time() * 1_000_000  # Get current time in microseconds
    
    rotation_end_event.set()
    line_iter = 0
    
    one_rot_time = current_count - counter_1
    time_per_deg = one_rot_time / 360.0
    delay_time_micro = time_per_deg*degs_per_line
    previous_micros = time.time() * 1_000_000
    # print("Line number {}".format(rot_number))
    rot_number = rot_number+1
    
    # Update frame
    if rot_number%rot_per_frame == 0:
        frame_iter = (frame_iter+1)%num_frames
    
            
    counter_1 = current_count


GPIO.add_event_detect(INTERRUPT_PIN, GPIO.RISING, callback=handle_interrupt_rising)
    
    
def LEDsLineTimerOptimized(line_num):
    line_iter_to_show = (line_num + LINES_TO_SHIFT + 2*NUM_DIVS)%NUM_DIVS
    global line_end_time, line_start_time, frame_colors, num_frames, frame_iter
    for i in range(NUM_LEDS_TO_USE):
        color = sequence_colors[frame_iter][line_iter_to_show][i]
        # print(color)
        strip.setPixelColor(i, color)

    # Show the LEDs
    strip.show()

    line_end_time = time.perf_counter()
    difference = (line_end_time - line_start_time)*1000000
    time_to_wait = delay_time_micro - difference
    if time_to_wait > 0:
        precise_micros_delay(time_to_wait)
    line_start_time = time.perf_counter()
    

def main():
    global line_to_show_colors, line_iter, rotation_end

    try:
        line_iter = 0
        while True:
            if rotation_end_event.is_set():
                rotation_end_event.clear()
                line_iter = 0
            
            LEDsLineTimerOptimized(line_iter)  # Call function to show the line
            line_iter = (line_iter + 1)%NUM_DIVS
            
                
    except KeyboardInterrupt:
        print("Exiting...")
        color = Color(0, 0, 0)
        for i in range(NUM_LEDS_TO_USE):
            strip.setPixelColor(i, color)
            strip.show()
            time.sleep(5.0/1000.0)
    finally:
        GPIO.cleanup()

if __name__ == "__main__":
    main()

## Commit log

2025-11-25 merged the forked repo to the old one
    [Blad v4.stl, Gear_1 v3.stl, Gear_2 v3.stl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]
2025-11-25 tester for sensor
2025-11-25 adding buttontest
2025-11-25 FINAALLY WOOOORKIIINNNNG at 500 rpm
2025-11-25 fix rotation 30 degree
    [config.py]
2025-11-25 Working also, with fixing the rotation ( a little)
    [config.py, pov_display.py]
